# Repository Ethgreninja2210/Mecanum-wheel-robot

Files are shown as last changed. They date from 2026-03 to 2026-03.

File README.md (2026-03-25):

# Mecanum-wheel-robot

I set out this project with not much idea where I was going but I knew I wanted to experiment with mechanum wheels and a robotic arm. I wanted this to be controlled by and ESP32 as I have not yet had a change to play with one of these and want to experiment further with the remote control and this seems like a wonderful chance to have these be like this. This set out the overall plan for the project which was for me to end with an RC car which has a small, light robotic arm and 4 mechanum wheels for funky movement.

## How To use/make

Start by printing the components from the STEP files (in the CAD folder) then test your electronics using the code (In the respective folder) and a breadboard to ensure all components are working (Wiring diagram bellow). After doing this, assemble the wheels and arm separately before placing the servos into the arm slots, these should be put asside for now.
To get started on the chassis, place the OLED into the case with the wires soldered BEFORE closing the case and then glue the back of the case into the slot on the main chassis. 
I then soldered up the motors and driver boards completely before sloting each motor into the respective arms, closing the arm lid and then glueing each bit into the chassis. 

Now go back to the arm and glue it into the chassis lid (there is an indent for it) and thread the servo wires through the slots before attaching them to the ESP along with the oled wires (If not already done) and screw the case shut with M3 Countersunk screws. 
Power the device, open the HTML file, and connect to the wifi (Password: 12345678) 











https://github.com/user-attachments/assets/f5a3482f-a923-4f8f-a1bb-3639411f3850


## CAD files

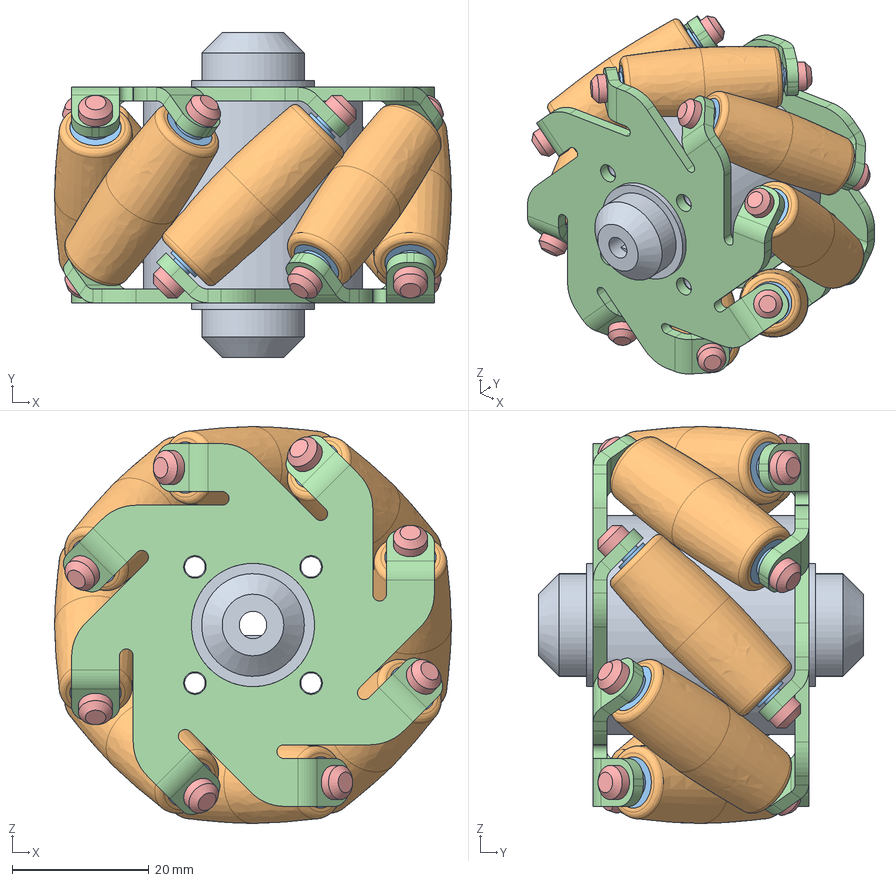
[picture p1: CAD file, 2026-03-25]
CAD/Wheel.STEP
58.0 x 47.5 x 58.0 mm
Internal connector
Roller x 8
Roller joint x 16
Side Panel x 2
miniwheel connector pin x 16

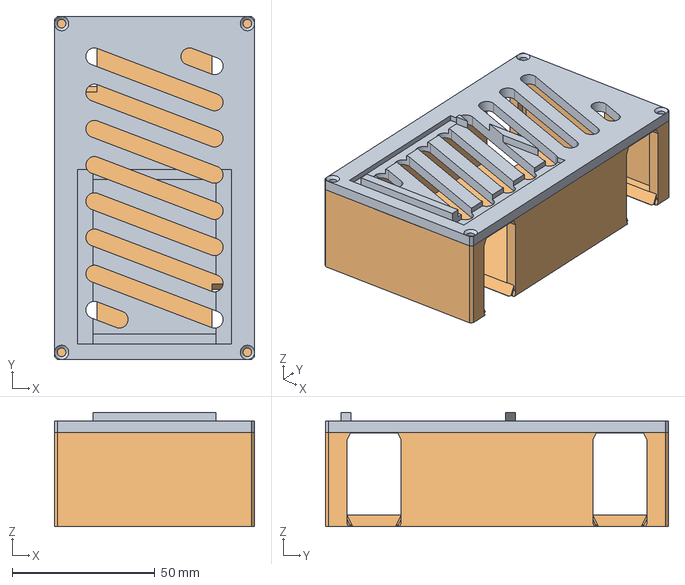
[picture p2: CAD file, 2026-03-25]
CAD/Chassis.STEP
70.0 x 120.0 x 40.0 mm

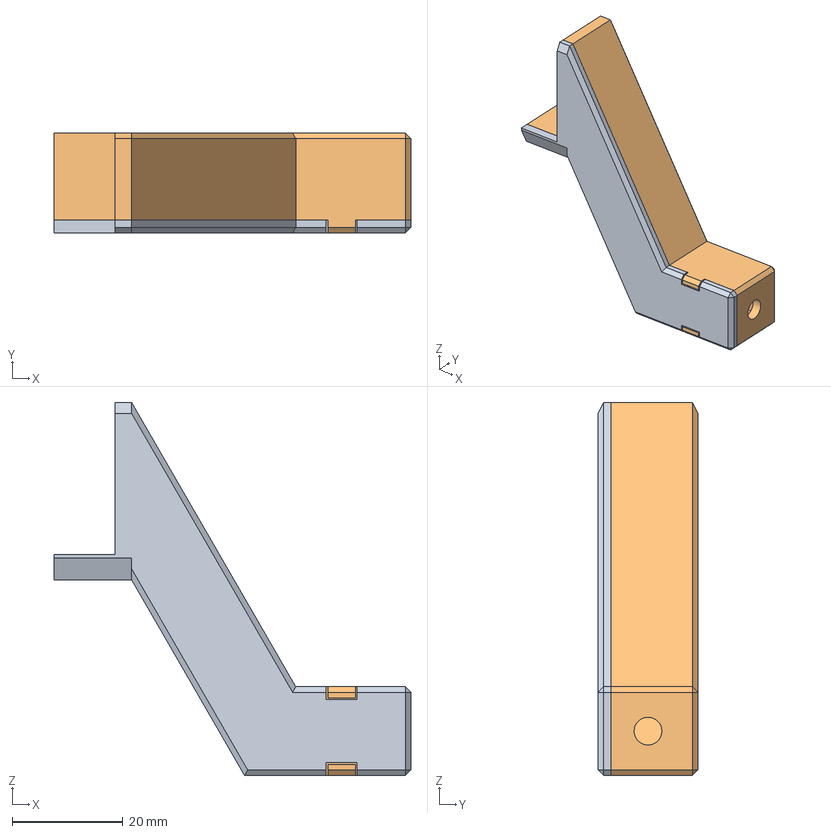
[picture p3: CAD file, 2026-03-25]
CAD/Leg_Struts.STEP
64.3 x 18.0 x 67.2 mm

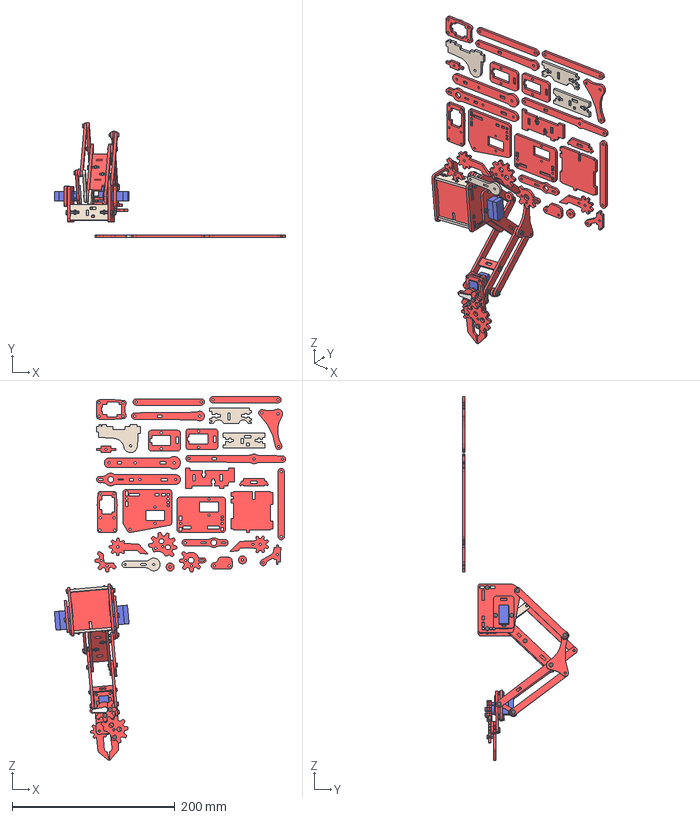
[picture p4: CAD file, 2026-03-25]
CAD/Arm.STEP
284.7 x 140.9 x 447.9 mm
House_base_wood
House_rear
House_front
House_mid_plate
Bolt_10
Servo
House_left_plate
Servo_clamp
Bolt_12
Bolt_12_1
Bolt_08
Bolt_08_1
Nut (1)
Nut (1)_1
Servo_1
House_right_plate x 2
Serco_clamp
Bolt_12_2
Bolt_12_3
Bolt_08_2
Bolt_08_3
Nut (1)_2
Nut (1)_3
Bolt_06
Bolt_12_4 x 3
Ring_1
Arm_short_left
Servo_arm_double
Arm_short_mid
Arm_long_mid x 2
Arm_long_right
Lower_connector_plate
Servo_arm_double_1
Nut (1)_4 x 2
Arm_lower_left x 2
Arm_mid_wood x 2
Upper_connection_plate
Arm_upper_right
Bolt_06_1
Bolt_06_2
Bolt_08_4
Bolt_08_5
Arm_upper_left
Ring
Triangle_wood
Bolt_10_1
Bolt_10_2
Bolt_06_3
Arm_gripper x 2
Gripper_plate
Gripper_servo_clamp
Servo_2
Gripper_clamp_left
Gripper_handle
Bolt_08_6
Bolt_08_7
Bolt_08_8
Bolt_08_9
Ring (1)
Bolt_10_3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

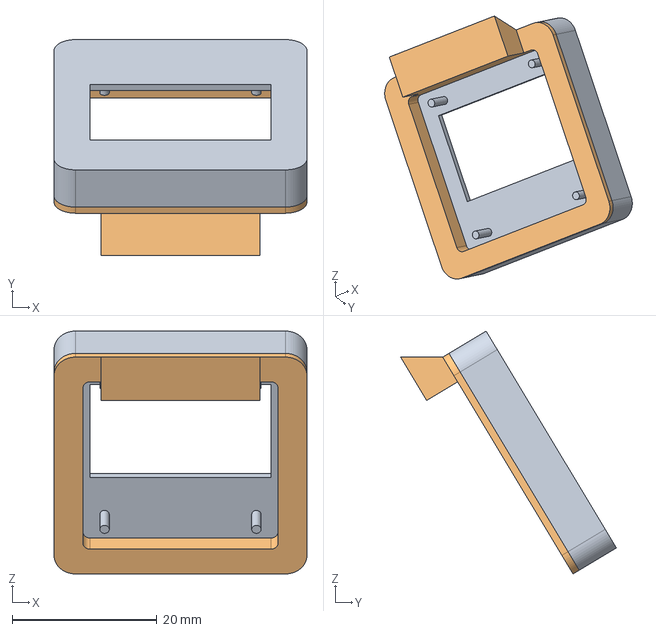
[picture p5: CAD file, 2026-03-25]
CAD/OLED_Cover.STEP
35.0 x 29.9 x 33.6 mm

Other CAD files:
CAD/F3d files/Chasis.f3z
CAD/F3d files/Leg struts.f3d
CAD/F3d files/Mecanum Wheel Assembly.f3z
CAD/F3d files/OLED Cover.f3d

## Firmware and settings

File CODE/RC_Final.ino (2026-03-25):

#include <Arduino.h>
#include <WiFi.h>
#include <WebSocketsServer.h>
#include <ArduinoJson.h>
#include <Wire.h>
#include <Adafruit_GFX.h>
#include <Adafruit_SSD1306.h>
#include <ESP32Servo.h>

/* =========================
   WiFi Access Point
   ========================= */
const char *ssid = "RC car";
const char *password = "12345678";

WebSocketsServer webSocket(81);

/* =========================
   OLED Display
   ========================= */
#define SCREEN_WIDTH 128
#define SCREEN_HEIGHT 64
Adafruit_SSD1306 display(SCREEN_WIDTH, SCREEN_HEIGHT, &Wire, -1);

/* =========================
   Motor Pins
   ========================= */
// Driver 1
#define D1_A_IN1 25
#define D1_A_IN2 26
#define D1_B_IN1 27
#define D1_B_IN2 14

// Driver 2
#define D2_A_IN1 18
#define D2_A_IN2 19
#define D2_B_IN1 32
#define D2_B_IN2 33

/* =========================
   Servo Pins
   ========================= */
#define SERVO1_PIN 16
#define SERVO2_PIN 17
#define SERVO3_PIN 23

Servo servo1;
Servo servo2;
Servo servo3;

// Default centre position for all servos (degrees)
int servo1Pos = 90;
int servo2Pos = 90;
int servo3Pos = 90;

/* =========================
   Ramping
   ========================= */
#define RAMP_STEP 5
#define LOOP_DELAY 5

int targetLeft  = 0;
int targetRight = 0;
int currentLeft  = 0;
int currentRight = 0;

/* =========================
   Eye Animation Variables
   ========================= */
float eyeOffset = 0;
float eyeTarget = 0;
unsigned long lastEyeMove = 0;

bool blinking = false;
int blinkLevel = 0;
unsigned long lastBlinkTime = 0;

bool startupDone = false;
unsigned long lastStartupFrame = 0;
int startupBlocks = 0;

/* =========================
   WiFi Animation Variables
   ========================= */
int wifiClients = 0;
int wifiAnimFrame = 0;
unsigned long lastWifiCheck = 0;
unsigned long lastWifiAnim  = 0;
bool wifiPulse = false;
unsigned long wifiPulseStart = 0;

/* =========================
   Motor Control
   ========================= */
void setMotorA(int speed) {
  if (speed > 0) {
    digitalWrite(D1_A_IN1, HIGH); digitalWrite(D1_A_IN2, LOW);
    digitalWrite(D2_A_IN1, HIGH); digitalWrite(D2_A_IN2, LOW);
  } else if (speed < 0) {
    digitalWrite(D1_A_IN1, LOW);  digitalWrite(D1_A_IN2, HIGH);
    digitalWrite(D2_A_IN1, LOW);  digitalWrite(D2_A_IN2, HIGH);
  } else {
    digitalWrite(D1_A_IN1, LOW);  digitalWrite(D1_A_IN2, LOW);
    digitalWrite(D2_A_IN1, LOW);  digitalWrite(D2_A_IN2, LOW);
  }
}

void setMotorB(int speed) {
  if (speed > 0) {
    digitalWrite(D1_B_IN1, HIGH); digitalWrite(D1_B_IN2, LOW);
    digitalWrite(D2_B_IN1, HIGH); digitalWrite(D2_B_IN2, LOW);
  } else if (speed < 0) {
    digitalWrite(D1_B_IN1, LOW);  digitalWrite(D1_B_IN2, HIGH);
    digitalWrite(D2_B_IN1, LOW);  digitalWrite(D2_B_IN2, HIGH);
  } else {
    digitalWrite(D1_B_IN1, LOW);  digitalWrite(D1_B_IN2, LOW);
    digitalWrite(D2_B_IN1, LOW);  digitalWrite(D2_B_IN2, LOW);
  }
}

int ramp(int current, int target) {
  if (current < target) {
    current += RAMP_STEP;
    if (current > target) current = target;
  } else if (current > target) {
    current -= RAMP_STEP;
    if (current < target) current = target;
  }
  return current;
}

/* =========================
   WiFi Icon
   ========================= */
void drawWiFiIcon() {
  if (millis() - lastWifiCheck > 500) {
    lastWifiCheck = millis();
    int newCount = WiFi.softAPgetStationNum();
    if (newCount != wifiClients) {
      wifiPulse = true;
      wifiPulseStart = millis();
    }
    wifiClients = newCount;
  }

  if (millis() - lastWifiAnim > 150) {
    lastWifiAnim = millis();
    wifiAnimFrame++;
    if (wifiAnimFrame > 3) wifiAnimFrame = 0;
  }

  int x = 120, y = 10;

  if (wifiClients == 0) {
    if (wifiAnimFrame % 2 == 0) {
      display.drawLine(x-4, y-4, x+4, y+4, SSD1306_WHITE);
      display.drawLine(x+4, y-4, x-4, y+4, SSD1306_WHITE);
    }
  } else {
    if (wifiAnimFrame >= 1) display.drawCircle(x, y, 2, SSD1306_WHITE);
    if (wifiAnimFrame >= 2) display.drawCircle(x, y, 4, SSD1306_WHITE);
    if (wifiAnimFrame >= 3) display.drawCircle(x, y, 6, SSD1306_WHITE);
  }

  if (wifiPulse) {
    display.drawCircle(x, y, 8, SSD1306_WHITE);
    if (millis() - wifiPulseStart > 400) wifiPulse = false;
  }
}

/* =========================
   Eyes + Blink
   ========================= */
void updateEyes() {
  if (!startupDone) return;

  if (millis() - lastEyeMove > 20) {
    lastEyeMove = millis();
    if (abs(eyeOffset - eyeTarget) < 1) {
      // Clamped to ±10 to prevent eye overflow off screen edges
      eyeTarget = random(-10, 10);
    }
    eyeOffset += (eyeTarget - eyeOffset) * 0.05;
  }

  if (millis() - lastBlinkTime > random(3000, 6000)) {
    blinking = true;
    lastBlinkTime = millis();
  }

  if (blinking) {
    blinkLevel += 3;
    if (blinkLevel > 30) {
      blinkLevel = 0;
      blinking = false;
    }
  }

  display.clearDisplay();

  int eyeWidth  = 30;
  int eyeHeight = 30 - blinkLevel;
  int baseY     = 17 + blinkLevel / 2;
  int leftX     = 34 + (int)eyeOffset;
  int rightX    = 84 + (int)eyeOffset;

  display.fillRoundRect(leftX,  baseY, eyeWidth, eyeHeight, 8, SSD1306_WHITE);
  display.fillRoundRect(rightX, baseY, eyeWidth, eyeHeight, 8, SSD1306_WHITE);

  drawWiFiIcon();
  display.display();
}

/* =========================
   Startup Animation
   (millis-based — no delay)
   ========================= */
void startupAnimation() {
  if (startupDone) return;

  if (millis() - lastStartupFrame < 40) return;
  lastStartupFrame = millis();

  display.clearDisplay();

  for (int i = 0; i < startupBlocks; i++) {
    int x = random(0, SCREEN_WIDTH  - 10);
    int y = random(0, SCREEN_HEIGHT - 10);
    display.fillRect(x, y, 10, 10, SSD1306_WHITE);
  }

  display.display();
  startupBlocks++;

  if (startupBlocks > 40) {
    startupDone = true;
    display.clearDisplay();
    display.display();
  }
}

/* =========================
   WebSocket Control
   ========================= */
void webSocketEvent(uint8_t num, WStype_t type,
                    uint8_t *payload, size_t length) {

  // Zero motors on disconnect (dead-man's switch)
  if (type == WStype_DISCONNECTED) {
    targetLeft  = 0;
    targetRight = 0;
    return;
  }

  if (type != WStype_TEXT) return;

  // Increased doc size to hold servo fields
  StaticJsonDocument<300> doc;
  if (deserializeJson(doc, payload)) return;

  // --- Motors ---
  float x     = doc["x"]     | 0.0f;
  float y     = doc["y"]     | 0.0f;
  int   speed = doc["speed"] | 0;

  targetLeft  = constrain((int)((y + x) * speed), -255, 255);
  targetRight = constrain((int)((y - x) * speed), -255, 255);

  // --- Servos (0-180 degrees, default 90 if key absent) ---
  if (doc.containsKey("s1")) servo1Pos = constrain((int)doc["s1"], 0, 180);
  if (doc.containsKey("s2")) servo2Pos = constrain((int)doc["s2"], 0, 180);
  if (doc.containsKey("s3")) servo3Pos = constrain((int)doc["s3"], 0, 180);

  servo1.write(servo1Pos);
  servo2.write(servo2Pos);
  servo3.write(servo3Pos);
}

/* =========================
   Setup
   ========================= */
void setup() {
  Serial.begin(115200);
  randomSeed(esp_random());   // Proper random seed on ESP32

  // Motor pins
  pinMode(D1_A_IN1, OUTPUT); pinMode(D1_A_IN2, OUTPUT);
  pinMode(D1_B_IN1, OUTPUT); pinMode(D1_B_IN2, OUTPUT);
  pinMode(D2_A_IN1, OUTPUT); pinMode(D2_A_IN2, OUTPUT);
  pinMode(D2_B_IN1, OUTPUT); pinMode(D2_B_IN2, OUTPUT);

  // Servos — ESP32Servo allocates its own PWM timers
  ESP32PWM::allocateTimer(0);
  ESP32PWM::allocateTimer(1);
  ESP32PWM::allocateTimer(2);

  servo1.setPeriodHertz(50);
  servo2.setPeriodHertz(50);
  servo3.setPeriodHertz(50);

  servo1.attach(SERVO1_PIN, 500, 2400);  // min/max pulse width µs for MG90
  servo2.attach(SERVO2_PIN, 500, 2400);
  servo3.attach(SERVO3_PIN, 500, 2400);

  // Centre all servos on boot
  servo1.write(90);
  servo2.write(90);
  servo3.write(90);

  // OLED
  Wire.begin(21, 22);
  if (!display.begin(SSD1306_SWITCHCAPVCC, 0x3C)) {
    Serial.println("SSD1306 init failed");
    while (true);
  }

  // WiFi AP
  WiFi.mode(WIFI_AP);
  WiFi.softAP(ssid, password);
  Serial.print("AP IP: ");
  Serial.println(WiFi.softAPIP());

  webSocket.begin();
  webSocket.onEvent(webSocketEvent);
}

/* =========================
   Loop
   ========================= */
void loop() {
  webSocket.loop();

  currentLeft  = ramp(currentLeft,  targetLeft);
  currentRight = ramp(currentRight, targetRight);

  setMotorA(currentLeft);
  setMotorB(currentRight);

  startupAnimation();
  updateEyes();

  delay(LOOP_DELAY);
}

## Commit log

2026-03-25 Create Arm
2026-03-25 Create Leg Struts
2026-03-25 Create Chassis
2026-03-25 Create BOM
2026-03-26 Update print statement from 'Hello' to 'Goodbye'
    [Leg_Struts.STEP]
2026-03-26 Create Wheel
2026-03-26 Update fmt.Println to print 'Goodbye World'
    [OLED_Cover.STEP]
